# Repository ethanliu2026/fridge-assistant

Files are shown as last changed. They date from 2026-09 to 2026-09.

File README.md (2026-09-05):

# fridge-assistant
**An on-device smart fridge assistant that detects food and suggests recipes — no cloud, no subscription.**

FridgeAssistant is a physical-computing system that identifies the ingredients in your fridge using a custom-trained computer-vision model, then generates a cuisine-specific recipe from them using a language model running **entirely locally** on a Raspberry Pi 5. A 3D-printed robotic arm swings a camera into the fridge to scan, then retracts.

Everything runs offline on ~$150 of hardware — compared to $3,000+ smart fridges that depend on the cloud and still don't generate recipes.

<!-- 👇 REPLACE with your demo GIF/video. A short clip of "press deploy → arm scans → recipe appears" is the single most valuable thing in this README. -->
<!-- ![demo](media/demo.gif) -->
Watch the full video: https://youtu.be/iBZBi5uDBYY

---

## What it does

1. Pick a cuisine (Chinese / Italian / Japanese) with a button
2. Press **Deploy** — a 3D-printed arm swings a camera down into the fridge
3. A **custom-trained YOLOv8 model** detects food items in the live camera feed
4. Press **Deploy** again to lock the detected ingredients
5. The ingredient list is sent to **Llama 3.2 (3B)**, running locally via **Ollama**, which returns a recipe — dish name, method, and any missing ingredients
6. The recipe shows on screen; pressing **Deploy** once more retracts the arm

The model is trained to recognize 10 real fridge ingredients: **cabbage, carrot, chicken, cucumber, egg, garlic, mushroom, onion, potato, zucchini.**

## Why I built it

People open the fridge without knowing what they have or what to cook — leading to food waste, duplicate grocery runs, and unnecessary takeout. Existing options don't solve it well: smart fridges cost thousands and rely on the cloud, and pantry apps need you to manually log every item (most people quit within a week). FridgeAssistant automates detection and runs fully offline, keeping everything private and cheap.

## Tech stack

**Software:** Python · YOLOv8 (Ultralytics) · ONNX Runtime · Ollama (Llama 3.2 3B) · OpenCV · Tkinter · gpiozero · Adafruit ServoKit
**Hardware:** Raspberry Pi 5 (16GB) · Hailo-8L AI HAT+ · USB webcam · PCA9685 PWM driver · 4× MG90S servos · HW-131 power module (2× 18650)
**Fabrication:** 3D-printed arm links & camera mount (Fusion 360) · laser-cut acrylic base plate

## System architecture

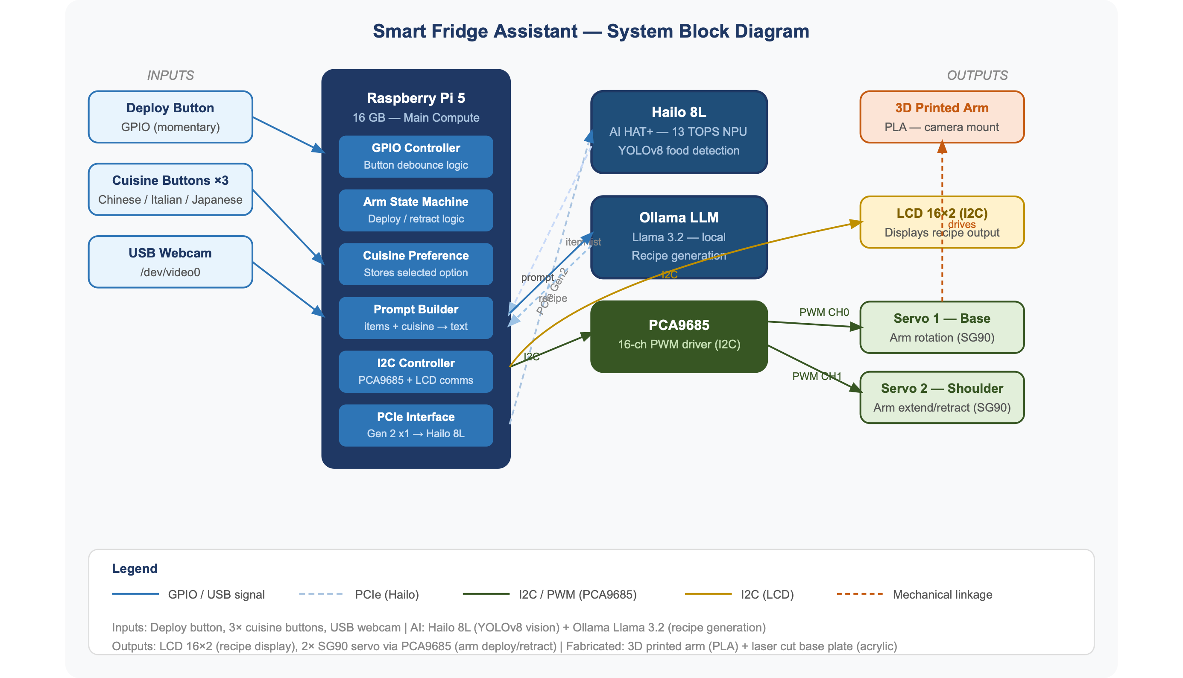
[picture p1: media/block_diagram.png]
System block diagram


```
Cuisine button → Pi 5 stores preference
Deploy button  → arm deploys (PCA9685 → 4× MG90S servos)
               → webcam captures fridge interior
               → YOLOv8 (best.onnx) detects food items
               → ingredient list + cuisine → Ollama (Llama 3.2)
               → recipe returned → displayed on screen
Deploy again   → arm retracts to parked position
```

The software runs **three concurrent threads**: the Tkinter UI loop, a camera-capture thread (~30 fps), and a detection thread (~1 fps) that runs inference on the latest frame. A three-state state machine (`IDLE → DEPLOYED → RECIPE`) drives the whole flow from a single deploy button.

## Design evolution

This was built across six iterations, each solving a concrete problem:

- **v1–v2** — Integrated the Hailo GStreamer pipeline with the UI and servos, using the stock COCO YOLOv8 model. Problems: GStreamer's signal handlers only work in the main thread, and the COCO model detected generic objects (donut, banana) rather than real fridge ingredients.
- **v3–v4** — Replaced the GStreamer pipeline with Ultralytics YOLO running a **custom-trained `best.onnx`** model on the CPU. Traded NPU acceleration for reliability and clean threading; added the 10 custom food classes.
- **v5** — Added the three-state state machine and fixed detection accumulation so items found across multiple frames persist instead of being overwritten. Integrated Ollama via `subprocess` with prompt engineering for a 3-sentence recipe.
- **v6 (final)** — Full three-thread architecture, smooth servo interpolation with I²C retry logic, ANSI-code stripping on the LLM output, and calibrated deploy/retract sequencing to avoid mechanical collision.

## Engineering challenges solved

A few of the more interesting problems from the build (full log in [`hardware/`](hardware/)):

- **I²C bus speed:** the Pi 5's I²C controller runs at 97.5 kHz — too fast for the PCF8574T LCD backpack (`Errno 121`). After trying baud-rate configs and a software-I²C overlay, pivoted to an HDMI display.
- **Servo torque:** SG90 servos overheated and stalled trying to lift the arm — upgraded to metal-gear MG90S.
- **Bus instability:** four servos moving at once crashed the I²C bus until a proper common ground was established between the HW-131 power module and the Pi.
- **UI freezing:** detection was blocking the UI thread — split camera capture and inference into separate threads.
- **Camera init:** the Pi needs a ~2 s delay after opening the USB camera or `VideoCapture` fails.

## Hardware & wiring

<details>
<summary>Raspberry Pi 5 pin assignments</summary>

| GPIO (BCM) | Physical Pin | Connected To | Function |
|---|---|---|---|
| GPIO 2 (SDA) | 3 | PCA9685 SDA | I²C data |
| GPIO 3 (SCL) | 5 | PCA9685 SCL | I²C clock |
| GPIO 17 | 11 | Button OUT 1 | Deploy |
| GPIO 27 | 13 | Button OUT 2 | Chinese cuisine |
| GPIO 22 | 15 | Button OUT 3 | Italian cuisine |
| GPIO 23 | 16 | Button OUT 4 | Japanese cuisine |
| 3.3V | 1 | Button VCC | Button logic power |
| GND | 6 | Common ground bus | Shared ground |

Buttons are **active-HIGH** (`pull_up=False`).

</details>

<details>
<summary>PCA9685 servo driver & power</summary>

| PCA9685 | Connected To | Notes |
|---|---|---|
| VCC | HW-131 3.3V | Logic power (not Pi 3.3V — insufficient current) |
| V+ | HW-131 5V | Servo power rail (external supply) |
| GND | Common ground bus | **Must** share ground with Pi for I²C stability |
| SDA / SCL | GPIO 2 / GPIO 3 | I²C |
| CH1–CH4 | 4× MG90S (signal only) | Channel map in code: `CHANNELS = [4, 1, 2, 3]` (CH0 was faulty) |

Power: 2× 18650 (7.4 V) → HW-131 buck module → 5 V servo rail + 3.3 V logic.

</details>

Fabrication files are in [`hardware/`](hardware/): arm links (`.stl`) and the base plate (`.dxf`).

## Running it

> ⚠️ This is built for a **Raspberry Pi 5 with attached servo hardware** — it won't run end-to-end on a normal computer without the arm, PCA9685, and camera. The code and model are provided for reference and reproduction.

```bash
# On a Raspberry Pi 5 with the hardware attached:
pip install ultralytics opencv-python pillow gpiozero adafruit-circuitpython-servokit

# Install Ollama and pull the model
curl -fsSL https://ollama.com/install.sh | sh
ollama pull llama3.2:3b

# Update the model path in fridge_assistant.py to point to best.onnx, then:
python fridge_assistant.py
```

## Repository contents

| File | Description |
|---|---|
| `fridge_assistant.py` | Final integrated application (v6) |
| `best.onnx` | Custom-trained YOLOv8 model (10 food classes) |
| `media/block_diagram.png` | System architecture diagram |
| `hardware/` | 3D-print (`.stl`) and laser-cut (`.dxf`) fabrication files |

---

*Built as the capstone for Advanced Physical Computing (2025–2026). Combines a custom-trained vision model and a locally-run LLM on embedded hardware into a single working physical system.*

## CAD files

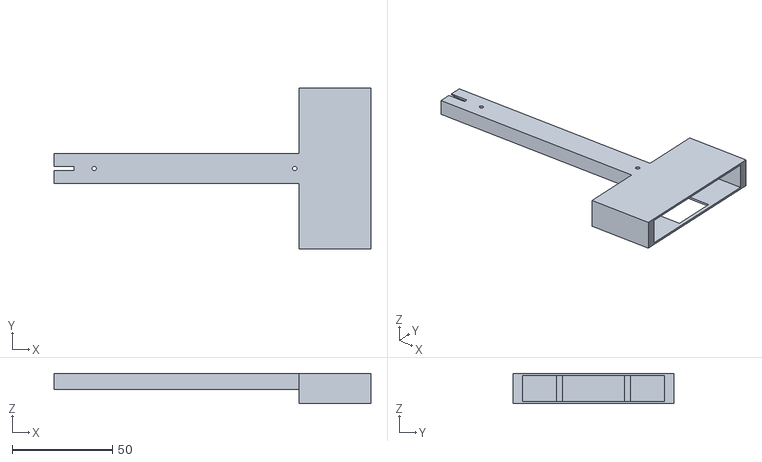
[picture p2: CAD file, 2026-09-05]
cad/link 1 v6.stl
158.0 x 80.0 x 15.0

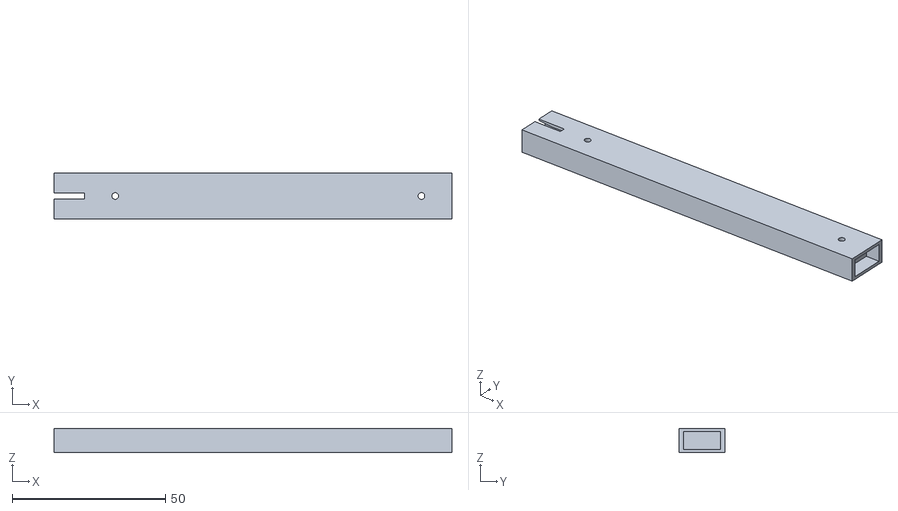
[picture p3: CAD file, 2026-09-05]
cad/link 2 v3.stl
130.0 x 15.0 x 8.00

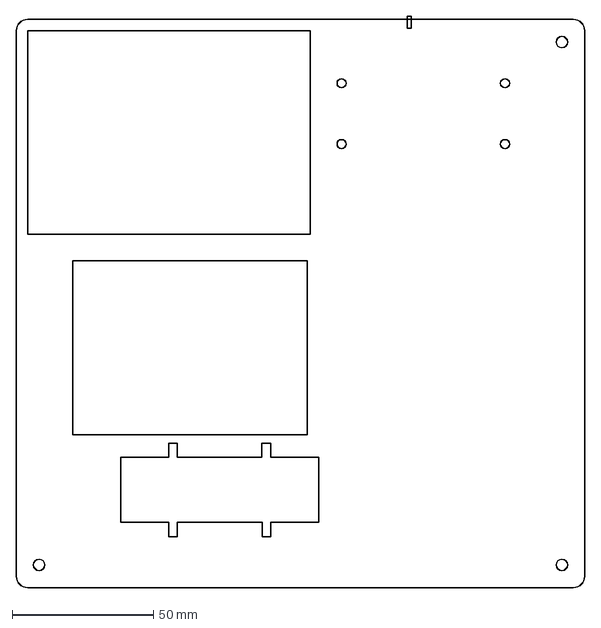
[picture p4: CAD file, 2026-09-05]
cad/APC base plate v3.dxf
201.1 x 202.1 mm

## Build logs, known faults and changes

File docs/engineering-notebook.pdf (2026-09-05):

Advanced Physical Computing 2025-2026 Capstone Project

## Smart Fridge Inventory & Recipe Assistant

Submitted by

## Ethan Liu

## Shanghai American School Puxi

Date: April 2026

Platform: Raspberry Pi 5 + Hailo 8L AI HAT+ + Ollama

### __________________________________________________________

## Table of Contents

### Executive Summary

The Smart Fridge Assistant is an AI-powered physical computing system that automatically identifies food ingredients in a refrigerator and generates cuisine-specific recipe suggestions. The system addresses a common daily problem: people open their fridge not knowing what to cook, leading to food waste, duplicate grocery purchases, and unnecessary takeout.

The system consists of a 3D-printed robotic arm mounted on a laser-cut base plate on top of a refrigerator. When the user presses the deploy button, the arm swings down into the fridge opening using four MG90S servos driven by a PCA9685 PWM driver. A USB webcam at the end of the arm captures the fridge interior. A custom-trained YOLOv8 object detection model running on the Raspberry Pi 5 identifies food items including eggs, potatoes, onions, carrots, garlic, mushrooms, cabbage, chicken, cucumber, and zucchini. The detected ingredients are passed to Ollama running Llama 3.2 3B locally on the Pi, which generates a recipe suggestion tailored to the user's selected cuisine preference (Chinese, Italian, or Japanese). The recipe — including dish name, preparation method, and any missing ingredients — is displayed on screen. Pressing the deploy button again retracts the arm to its parked position.
The system runs entirely offline with no cloud dependency, costs approximately $150 in hardware compared to $3,000+ smart fridge solutions, and responds in under 30 seconds from deploy to recipe display.

Key technical challenges overcome included Pi 5 I2C bus incompatibility with the LCD display, servo torque limitations requiring an upgrade from SG90 to MG90S, power instability from inadequate common grounding, and camera initialization timing issues. The Hailo-8 AI HAT+ is integrated into the system and detected successfully, providing the hardware foundation for future YOLOv8 NPU acceleration planned as an extension of this project.

## 1.Problem Statement

### 1.1 The Problem

People open their fridge multiple times a day not knowing what they have, what’s running low, or what they an cook with what’s available. This leads to food waste (buying duplicates of things already in the fridge), unnecessary grocery trips, and the daily frustration of staring into the fridge trying to decide what to make.

### 1.2 Target Customer

Anyone who cooks at home, particularly students living independently, busy families, and households where multiple people share a fridge and nobody tracks inventory.

### 1.3 Solution Usage

A camera mounted at the fridge door automatically scans visible food items when the door opens, identifies them using AI vision, and immediately suggests recipes based on what’s available. A physical indicator flags when stock is critically low.

## 2. Research

### 2.1 What already exists

- Samsung Family Hub fridge — built-in interior camera, app-based viewing, cloud processing, no recipe generation. Costs $3000+, requires internet, camera is fixed and fogs up from condensation.
- LG ThinQ fridge — similar concept, app-based, cloud dependent, expensive.
- Grocy / pantry apps — manual barcode scanning to log inventory. Relies entirely on user discipline — most people stop using it within a week.
- ChatGPT / recipe apps — require you to manually type what you have. No automatic detection.
- Fixed fridge cameras (e.g. FridgeCam) — small camera that mounts inside and photos contents when door closes. Still suffers from condensation, fixed angle, no AI processing.

### 2.2 What I Learned from Research

- COCO-trained YOLOv8 can detect ~20 common food items out of the box (banana, apple, orange, sandwich, bottle, cup, bowl, cake, carrot, hot dog, pizza, donut, broccoli) — sufficient for a meaningful demo
- Ollama can run Llama 3.2 or Gemma 3 locally on Pi 5 — response time is ~3-8 seconds for a short recipe suggestion, acceptable for this use case
- PCA9685 can drive multiple servos simultaneously over I2C from just 2 GPIO pins, solving the PWM pin limitation on Pi 5
- A 2-servo arm (base rotation + shoulder extension) is sufficient to move a lightweight USB camera from a parked position on top of the fridge to a scanning position inside the fridge opening

[Example] The following, Figure 1, depicts the three-view of the final unmanned system design.

[ADD FIGURE-CENTERED]

Figure 1. Three-view of final uncrewed system design.

## 3.System Architecture

### 3.1 Component List:

Component | Part | Role
Raspberry Pi 5 (16GB) | RPi 5 16GB | Main compute
Hailo 8L AI HAT+ | 13 TOPS NPU | Runs YOLOv8 food detection
USB Webcam | Logitech C270 or similar | Captures fridge interior
Push button (deploy) | Momentary tactile button | Triggers arm deploy/retract cycle
Push button (Chinese) | Momentary tactile button | Selects Chinese cuisine preference
Push button (Italian) | Momentary tactile button | Selects Italian cuisine preference

Push button (Japanese) | Momentary tactile button | Selects Japanese cuisine preference
PCA9685 PWM driver | Adafruit PCA9685 | Controls both servos over I2C
SG90 Servo 1 | SG90 | Base rotation (arm swings out over fridge)
SG90 Servo 2 | SG90 | Shoulder (arm extends down into fridge)
LCD 16x2 (I2C) | LCD1602 with I2C backpack | Displays detected items + recipe
3D printed arm | Bambu Lab PLA | Arm links + camera mount at end effector
Laser cut base plate | 3mm acrylic | Mounts PCA9685, Pi, and arm base to fridge top

### 3.2 Data Flow:

Cuisine button pressed (Chinese / Italian / Japanese) ↓
Pi 5 stores selected cuisine preference
↓
Deploy button pressed
↓
GPIO detects press → arm deploys
(PCA9685 → Servo 1 rotates out, Servo 2 extends down) ↓
Webcam captures frame of fridge interior
↓
Hailo 8L runs YOLOv8 inference on frame
↓
Detected food items list (class labels + confidence scores) ↓
Filter detections by confidence threshold (>0.5)
↓
Item list + cuisine preference formatted as prompt
→ sent to Ollama (Llama 3.2):
"Given these ingredients: [items]. Suggest a [cuisine] recipe."

↓
Ollama returns recipe suggestion
↓
LCD displays recipe (scrolling if text exceeds 2 lines)
↓
Deploy button pressed again → arm retracts to parked position (PCA9685 → Servo 2 retracts, Servo 1 rotates back)

### 3.3 Block Diagram

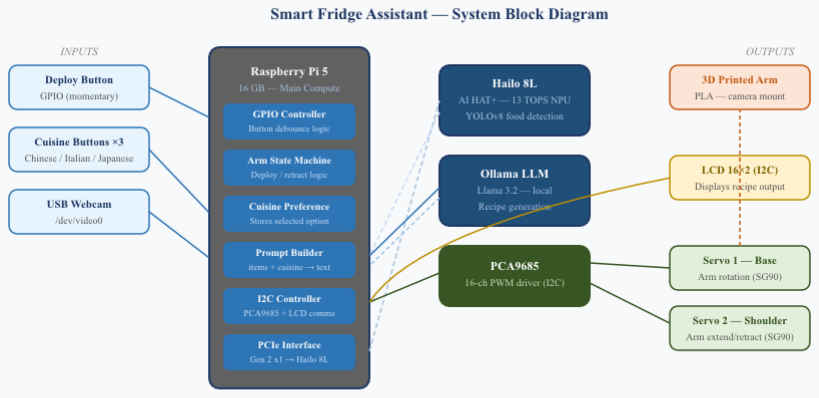
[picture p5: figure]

## 4. Wiring Diagram & Pin Assignment

### 4.1 Raspberry Pi Pin Assignment Table

GPIO (BCM) | Physical Pin | Connected To | Function
GPIO 2 (SDA) | Pin 3 | PCA9685 SDA, LCD SDA | I2C data
GPIO 3 (SCL) | Pin 5 | PCA9685 SCL, LCD SCL | I2C clock
GPIO 17 | Pin 11 | Button module OUT 1 | Deploy button
GPIO 27 | Pin 13 | Button module OUT 2 | Chinese cuisine
GPIO 22 | Pin 15 | Button module OUT 3 | Italian cuisine

GPIO 23 | Pin 16 | Button module OUT 4 | Japanese cuisine
3.3V | Pin 1 | Button module VCC | Button logic power
5V | Pin 2 | LCD VCC | LCD panel power
GND | Pin 6 | Common ground bus | Shared ground
USB-A | — | USB Webcam | Camera input
PCIe FPC | — | Hailo-8 AI HAT+ | NPU connection
HDMI | — | Monitor | Display output

### 4.2 PCA9685 PWM Driver Connections

PCA9685 Pin | Connected To | Notes
VCC | HW-131 3.3V output | Logic power — NOT Pi 3.3V (insufficient current)
GND | Common ground bus | Must share ground with Pi
SDA | GPIO 2 (Pi pin 3) | I2C data
SCL | GPIO 3 (Pi pin 5) | I2C clock
V+ | HW-131 5V output | Servo power rail — external supply required
CH1 PWM | MG90S Servo (middle joint 1) | Signal wire only
CH2 PWM | MG90S Servo (base joint 1) | Signal wire only
CH3 PWM | MG90S Servo (middle joint 2) | Signal wire only
CH4 PWM | MG90S Servo (base joint 2) | Signal wire only

### 4.3 HW-131 Power Module

HW-131 Pin | Connected To | Notes
Input+ | 18650 battery pack positive | 7.4V input from 2× NCR18650B
Input- | 18650 battery pack negative | —
5V output | PCA9685 V+ | Servo power
3.3V output | PCA9685 VCC | Logic power
GND | Pi GND (pin 6) + PCA9685 GND | Common ground — critical for I2C stability

## 5. Code Documentation & Explanation

### 5.1 Version History

### 5.1.1 fridge_assistant_v1-v2 (Early Versions)

Initial integration attempts combining the Hailo GStreamer pipeline with tkinter display and servo control. These versions used the default COCO YOLOv8 model running on the Hailo-8 NPU via the hailo-apps GStreamer pipeline.

Problems encountered:
- GStreamer pipeline requires signal handlers that only work in the main thread — running it in a background thread caused ValueError: signal only works in main thread
- Default COCO model detected general objects (person, donut, banana) but not realistic fridge ingredients
- LCD display integration failed due to Pi 5 I2C bus speed incompatibility

### 5.1.2 fridge_assistant_v3-v4 (ONNX Transition)

Replaced Hailo GStreamer pipeline with ultralytics YOLO running the custom-trained best.onnx model directly. This sacrifices NPU acceleration (model runs on CPU) in exchange for reliability and compatibility with threading.

Key change:
- Detection now uses YOLO('/home/stussy/Downloads/best.onnx', task='detect') with onnxruntime backend. Runs at approximately 1 frame per second on Pi 5 CPU, acceptable for a fridge scanning use case.
- Added custom food classes from trained dataset: cabbage, carrot, chicken, cucumber, egg, garlic, mushroom, onion, potato, zucchini.

### 5.1.3 fridge_assistant_v5 (State Machine)

Introduced a 3-state state machine to control program flow:

## STATE_IDLE → (deploy press) → STATE_DEPLOYED → (deploy press) → STATE_RECIPE → (deploy press) → STATE_IDLE

- STATE_IDLE: Arm parked, waiting for user input
- STATE_DEPLOYED: Arm down, camera scanning, detections accumulate across frames
- STATE_RECIPE: Items locked, Ollama generating recipe, displaying result

Detection accumulation fix: Changed user_data.live_items = list(set(items)) to user_data.live_items = list(set(user_data.live_items + items)) so items detected across multiple frames are preserved rather than replaced each frame.
Ollama integration: Uses subprocess.run(['ollama', 'run', 'llama3.2:3b', prompt]) with 120s timeout. Prompt engineered to return dish name, cooking description, and missing ingredients in 3 sentences.

### 5.1.4 fridge_assistant_v6 (Final Version)

Final integrated script with all features working:
Architecture — 3 concurrent threads:
- Main thread: tkinter event loop and UI updates
- run_camera: captures frames at 30fps, stores in user_data.latest_frame
- run_detection: runs YOLO inference at 1fps using latest frame, updates detected items

Key Functions:
- move_joint(indices, targets, steps, delay) — smooth servo interpolation. Takes position indices (0-3) mapped through CHANNELS=[4,1,2,3] to actual PCA9685 channels. Moves in 15 steps with 0.08s delay between steps for smooth motion. Includes retry logic for I2C errors.
- deploy_arm() / retract_arm() — sequence control. Deploy moves middle joint first then base to avoid mechanical collision. Retract reverses: middle first, then base.
- on_deploy() — state machine transition handler. Single button controls all three state transitions depending on current state.

- get_recipe() — runs in separate thread to avoid blocking UI. Strips ANSI escape codes from Ollama output using re.sub(r'\x1b\[[0-9;]*m', '', recipe) before displaying.
- update_camera() — tkinter after() callback running every 50ms, converts OpenCV BGR frame to PIL ImageTk for display in left panel.
- CHANNELS mapping: CHANNELS = [4, 1, 2, 3] maps position indices to PCA9685 channels. Index 0 = CH4 (base servo 1), Index 1 = CH1 (middle servo 1), Index 2 = CH2 (base servo 2), Index 3 = CH3 (middle servo 2). CH0 was found to be faulty and replaced with CH4.

### 5.2 Final Code (v6)

import cv2 import subprocess import time import threading import tkinter as tk from PIL import Image, ImageTk from gpiozero import Button from adafruit_servokit import ServoKit from ultralytics import YOLO

SERVO SETUP

kit = ServoKit(channels=16) for ch in [1, 2, 3, 4]: kit.servo[ch].set_pulse_width_range(600, 2400) time.sleep(0.5)

CHANNELS = [4, 1, 2, 3] PARKED = [65, 125, 97, 20] DEPLOYED = [115, 75, 47, 70]

pos = PARKED[:]

def set_servo(ch, angle): angle = max(0, min(180, int(angle))) for attempt in range(4): try: kit.servo[ch].angle = angle return except Exception as e: print(f"CH{ch} retry {attempt+1}: {e}") time.sleep(0.3)

def move_joint(indices, targets, steps=15, delay=0.08): start = pos[:] for i in range(1, steps + 1): for idx in indices: new = int(start[idx] + (targets[idx] - start[idx]) * i / steps) new = max(0, min(180, new)) set_servo(CHANNELS[idx], new) time.sleep(0.04) time.sleep(delay) for idx in indices: pos[idx] = targets[idx]

def deploy_arm(): display("Deploying arm...") mid_targets = pos[:] mid_targets[1] = DEPLOYED[1] mid_targets[3] = DEPLOYED[3] move_joint([1, 3], mid_targets) time.sleep(0.5) base_targets = pos[:] base_targets[0] = DEPLOYED[0] base_targets[2] = DEPLOYED[2] move_joint([0, 2], base_targets)

def retract_arm(): display("Retracting...") base_targets = pos[:] base_targets[0] = PARKED[0] base_targets[2] = PARKED[2] move_joint([0, 2], base_targets) time.sleep(0.5) mid_targets = pos[:] mid_targets[1] = PARKED[1] mid_targets[3] = PARKED[3] move_joint([1, 3], mid_targets)

DISPLAY SETUP

root = tk.Tk() root.title("Fridge Assistant") root.configure(bg="black") root.attributes('-fullscreen', True) root.update() SW = root.winfo_width() SH = root.winfo_height()

Left panel — camera feed

cam_label = tk.Label(root, bg="black") cam_label.place(x=0, y=0, width=SW//2, height=SH)

Right panel — info

right = tk.Frame(root, bg="black") right.place(x=SW//2, y=0, width=SW//2, height=SH)

tk.Label(right, text="Fridge Assistant", font=("Arial", 32, "bold"), bg="black", fg="white").pack(pady=20)

cuisine_label = tk.Label(right, text="Cuisine: Chinese", font=("Arial", 22), bg="black", fg="yellow") cuisine_label.pack(pady=5)

status_label = tk.Label(right, text="Select cuisine → Deploy", font=("Arial", 18), bg="black", fg="green") status_label.pack(pady=5)

detected_label = tk.Label(right, text="", font=("Arial", 16), bg="black", fg="cyan", wraplength=SW//2 -
40) detected_label.pack(pady=5)

recipe_label = tk.Label(right, text="", font=("Arial", 15), bg="black", fg="white", wraplength=SW//2 - 40, justify="left") recipe_label.pack(pady=10, padx=20)

hint_label = tk.Label(right, text="", font=("Arial", 14, "italic"), bg="black", fg="gray") hint_label.pack(pady=5)

QUIT BUTTON

quit_btn = tk.Button(right, text="✕ Quit", font=("Arial", 14), bg="#333333", fg="white", relief="flat", command=lambda: quit_program()) quit_btn.pack(side="bottom", pady=20)

def display(status="", recipe="", detected="", hint=""): status_label.config(text=status) recipe_label.config(text=recipe) detected_label.config(text=detected) hint_label.config(text=hint) root.update()

def quit_program(): print("Quitting...") retract_arm() root.destroy()

STATE

STATE_IDLE = 0 STATE_DEPLOYED = 1 STATE_RECIPE = 2 state = STATE_IDLE

class UserData: def init(self): self.live_items = [] self.locked_items = [] self.cuisine = "Chinese" self.latest_frame = None

user_data = UserData()

CAMERA FEED UPDATE

def update_camera(): if user_data.latest_frame is not None: frame = user_data.latest_frame.copy() frame = cv2.cvtColor(frame, cv2.COLOR_BGR2RGB) h, w = frame.shape[:2] # Scale to fit left panel panel_w = SW // 2 panel_h = SH scale = min(panel_w / w, panel_h / h) new_w = int(w * scale) new_h = int(h * scale) frame = cv2.resize(frame, (new_w, new_h)) img = ImageTk.PhotoImage(Image.fromarray(frame)) cam_label.config(image=img) cam_label.image = img root.after(50, update_camera)

DETECTION LOOP

def run_detection(): model = YOLO('/home/stussy/Downloads/best.onnx', task='detect') cap = cv2.VideoCapture(0) FOOD_CLASSES = { "cabbage", "carrot", "chicken", "cucumber", "egg", "garlic", "mushroom", "onion", "potato", "zucchini" }

while True:
ret, frame = cap.read() if not ret: time.sleep(0.1)
continue

if state == STATE_DEPLOYED:
results = model(frame, verbose=False) items = []
for r in results:
for box in r.boxes:
label = model.names[int(box.cls)]
conf = float(box.conf)
if conf > 0.35 and label in FOOD_CLASSES: items.append(label)
# Draw box on frame

x1, y1, x2, y2 = map(int, box.xyxy[0]) cv2.rectangle(frame, (x1, y1), (x2, y2), (0, 255, 255), 2) cv2.putText(frame, f"{label} {conf:.2f}",
(x1, y1 - 8), cv2.FONT_HERSHEY_SIMPLEX, 0.5, (0, 255, 255), 2)

if items:
user_data.live_items = list(set(user_data.live_items + items)) items_str = ", ".join(sorted(user_data.live_items)) detected_label.config(text=f"Detected: {items_str}") root.update()

user_data.latest_frame = frame
time.sleep(0.05)

OLLAMA def get_recipe(): items_str = ", ".join(sorted(user_data.locked_items)) display( "Generating recipe...", detected=f"Locked: {items_str}", hint="Please wait..." ) prompt = ( f"I found these ingredients in my fridge: {items_str}. " f"Suggest ONE simple {user_data.cuisine} recipe I could make. " f"In 3 sentences: name the dish, briefly describe how to make it, " f"then list any extra ingredients I would need." ) try: result = subprocess.run( ["ollama", "run", "llama3.2:3b", prompt], capture_output=True, text=True, timeout=120 ) recipe = result.stdout.strip() display( f"{user_data.cuisine} Recipe", recipe=recipe, detected=f"Ingredients: {items_str}", hint="Press Deploy to retract arm" ) except Exception as e: display("Ollama error", recipe=str(e)[:80])

BUTTON CALLBACKS

def on_deploy(): global state
if state == STATE_IDLE:
state = STATE_DEPLOYED
user_data.live_items = []
def do_deploy():
deploy_arm()
display(
"Scanning fridge...",
detected="Looking for food...",
hint="Press Deploy again to lock items & get recipe" )
threading.Thread(target=do_deploy, daemon=True).start()

elif state == STATE_DEPLOYED:
if not user_data.live_items:
display("No food detected!", hint="Try adjusting camera angle") return
state = STATE_RECIPE
user_data.locked_items = user_data.live_items[:] threading.Thread(target=get_recipe, daemon=True).start()

elif state == STATE_RECIPE:

state = STATE_IDLE
user_data.live_items = []
user_data.locked_items = []
def do_retract():
retract_arm()
display("Ready!", hint="Select cuisine then press Deploy") threading.Thread(target=do_retract, daemon=True).start()

def on_chinese(): user_data.cuisine = "Chinese" cuisine_label.config(text="Cuisine: Chinese") root.update()

def on_italian(): user_data.cuisine = "Italian" cuisine_label.config(text="Cuisine: Italian") root.update()

def on_japanese(): user_data.cuisine = "Japanese" cuisine_label.config(text="Cuisine: Japanese") root.update()

btn_deploy = Button(17, pull_up=False) btn_chinese = Button(27, pull_up=False) btn_italian = Button(22, pull_up=False) btn_japanese = Button(23, pull_up=False)

btn_deploy.when_pressed = on_deploy btn_chinese.when_pressed = on_chinese btn_italian.when_pressed = on_italian btn_japanese.when_pressed = on_japanese

STARTUP

print("Starting Fridge Assistant...")

for i, ch in enumerate(CHANNELS): set_servo(ch, PARKED[i]) time.sleep(1.5)

display("Fridge Assistant ready!", hint="Select cuisine then press Deploy")

detection_thread = threading.Thread(target=run_detection, daemon=True) detection_thread.start()

root.after(100, update_camera)

MAIN LOOP try: root.mainloop() except KeyboardInterrupt: print("\nShutting down...") retract_arm() root.destroy()

## 6. Fusion 360 Design Files & Iteration Notes

### 6.1 Base Plate – 2 iterations

### 6.1.1 Iteration 1 (Cardboard)

Final integrated script with all features working:

A rough cardboard prototype with approximate hole positions for the base servos and PCA9685. This was used to verify the general layout and spacing before committing to a permanent material. Holes were laser-cut and approximate.

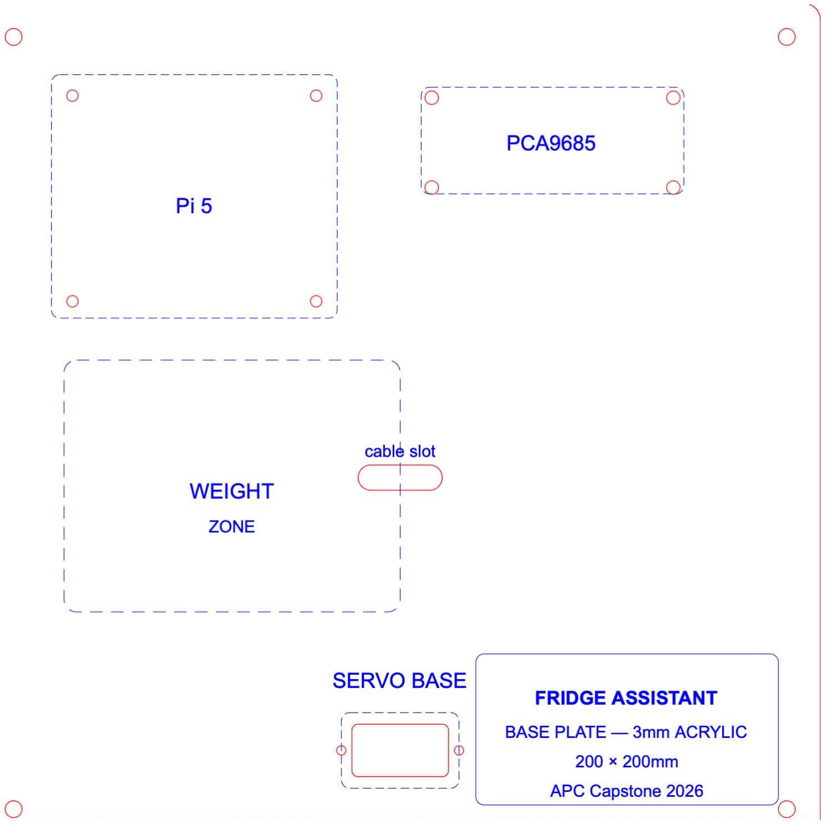
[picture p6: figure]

Figure 2. Iteration 1 of the Base Plate

### 6.1.2 Iteration 2 (Wood)

Final integrated script with all features working:

A rough cardboard prototype with approximate hole positions for the base servos and PCA9685. This was used to verify the general layout and spacing before committing to a permanent material. Holes were hand-cut and approximate — no precise measurements.

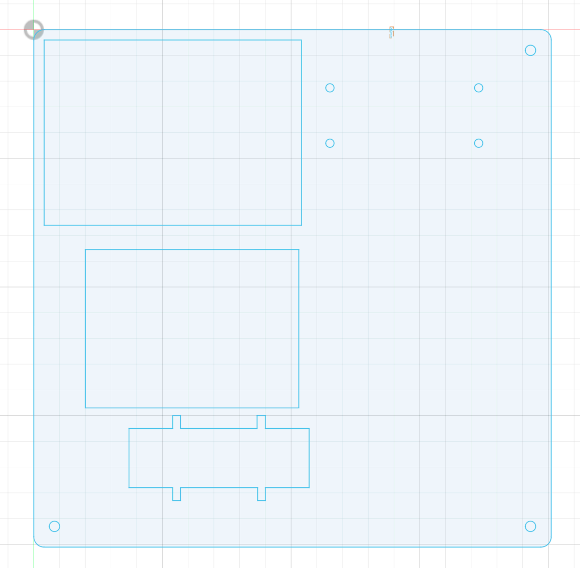
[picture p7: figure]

Figure 2. Iteration 2 of the Base Plate

Key learning: The cardboard prototype saved significant time — discovering that the servo spacing needed adjustment before cutting the final material avoided wasting a wood sheet.

### 6.2 Arm Links – 2 iterations

### 6.2.1 Iteration 1

Simple rectangular beam with flat ends. Connected to servo horns using hot glue — unreliable under torque and came loose during testing.

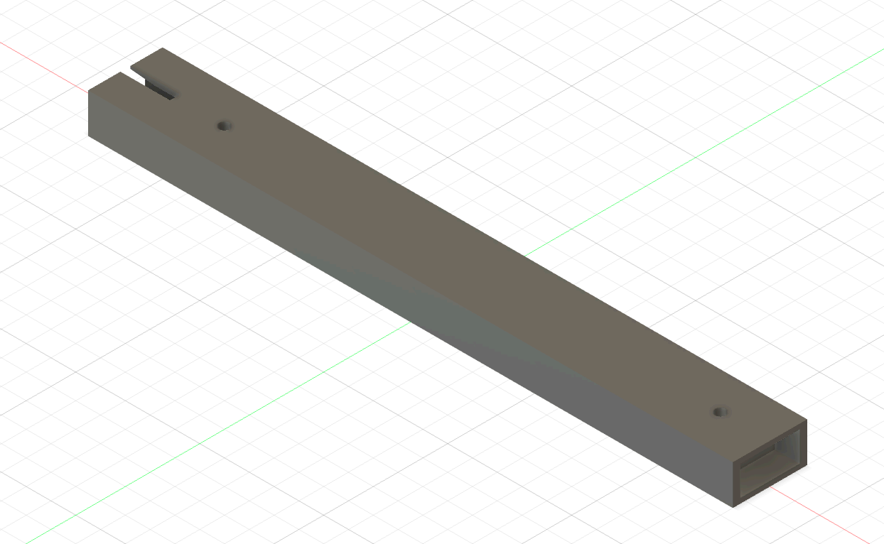
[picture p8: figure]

Figure 1. Iteration 1 of the Arm Link

### 6.2.2 Iteration 2

Added recessed slots at the joint ends sized to the servo horn profile, so the horn sits flush and is mechanically located before any adhesive is applied. For the dual-servo base joint, replaced the simple flat plate with measured slots that the MG90S servo bodies press-fit into precisely, eliminating reliance on hot glue for alignment.

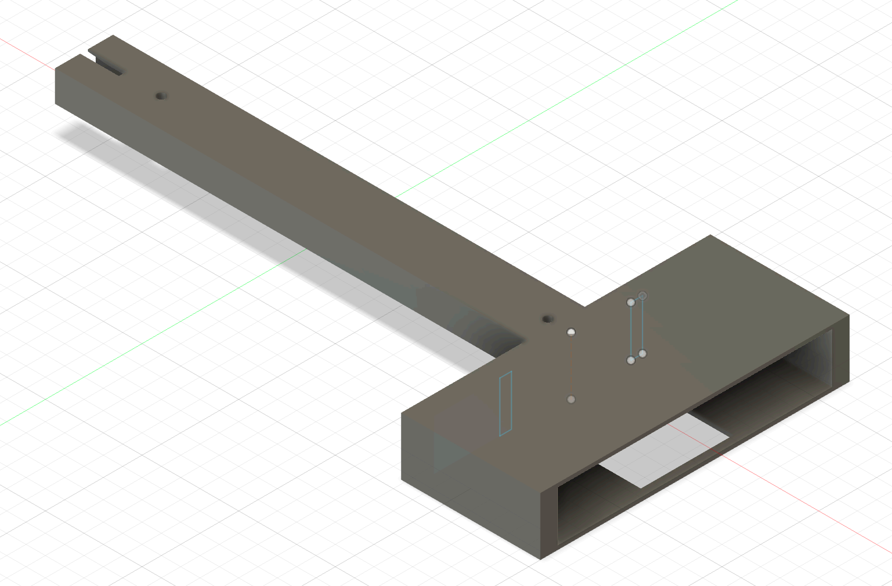
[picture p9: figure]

Figure 2. Iteration 2 of the Base Plate

Key learning: Mechanical location is far more reliable than adhesive alone under repeated servo movement. The press-fit slots made the joint significantly more stable.

## 7. Testing Logs

Date | Component | What was tested | Result | Fix applied
Mar | LCD (16×2 I2C) | Display text via RPLCD | Failed — OSError Errno 121 Remote I/O error | Discovered Pi 5 brcmstb I2C controller runs at 97.5kHz — too fast for PCF8574T. Attempted baudrate config, software I2C overlay.

| | | | Unresolved — pivoted to HDMI display
Mar | PCA9685 | i2cdetect | Detected at 0x40 ✓ | —
Mar | SG90 servos × 4 | Basic angle movement | Moved correctly individually | —
Mar | SG90 servos × 4 | All 4 moving simultaneously | I2C crashed mid-run (Errno 121) | Fixed common ground between HW-131 power module and Pi — voltage difference was causing bus instability
Mar | SG90 servos | Arm lift test | Servos overheated and stalled — insufficient torque to lift arm weight | Upgraded to MG90S metal gear servos
Mar | MG90S servos | Arm lift test | Successfully lifted arm ✓ | Calibrated PARKED and DEPLOYED angles per channel
Apr | Hailo-8 | hailortcli fw-control identify | Detected: Firmware 4.23.0, HAILO8 architecture ✓ | —
Apr | Buttons × 4 | GPIO input test | Initially read as always pressed | Changed pull_up=True to pull_up=False — button modules are active HIGH
Apr | Ollama | Recipe generation | Worked but slow (~30s) and initial timeout errors | Increased timeout to 120s, shortened prompt
Apr | Ollama output | Display on screen | Random characters appeared (□[7D□[K) | Stripped ANSI escape codes with regex
May | USB webcam | cv2.VideoCapture(0) | Failed — camera not found | Added 2-second delay after opening — Pi needs time to initialize USB camera

May | Custom YOLOv8 (5 epochs) | Potato detection | Detected as onion/donut | Retrained for 10 epochs — improved but still imperfect
May | Camera feed | Display in tkinter window | Frame frozen — detection blocking UI thread | Separated into two threads: run_camera (30fps) and run_detection (1fps)
May | Full system | End-to-end flow | Working ✓ | —

## 8. AI Usage Log

This project was developed with significant AI assistance through Claude (Anthropic). Below is a summary of how AI was used and the decisions made:
- Hardware debugging
- AI was used extensively to diagnose the I2C LCD issue. Claude identified that the Pi 5's new brcmstb I2C controller runs at a fixed 97.5kHz and doesn't respond to standard baudrate configuration — a known Pi 5-specific issue. Multiple approaches were suggested (baudrate config, software I2C overlay, different GPIO pins). When all failed, the decision to pivot to HDMI display was made by the student after weighing time cost vs. benefit.
- Code architecture
- Claude generated the initial script structure including the state machine (IDLE → DEPLOYED → RECIPE), servo movement functions with smooth interpolation, and the threading architecture separating camera capture from detection. The student made decisions about servo channel assignments, calibrated angles, and button GPIO pins based on physical testing.
- Servo calibration
- The calibration process was entirely student-driven — the student ran test scripts, physically observed servo movement, and reported back observed angles. AI provided the test code framework but the student determined all PARKED and DEPLOYED values through hands-on iteration.
- Detection and Ollama
- Claude suggested switching from the Hailo GStreamer pipeline to ultralytics ONNX inference when the pipeline couldn't run in a background thread. The student decided to use a Roboflow public dataset for training rather than building a custom dataset from scratch, based on time constraints. Prompt engineering for Ollama (asking for dish name, description, and missing ingredients) was a collaborative decision.
- Key principle
- AI was used as a technical reference and code generation tool. All hardware decisions, physical calibration, and design tradeoffs were made by the student based on real-world testing results.

## 9. Reflection

This project pushed me significantly beyond the scope of standard coursework. Building a system that combines physical robotics (a 4-servo arm driven by a PCA9685), computer vision (custom-trained YOLOv8), and a local language model (Ollama Llama 3.2) into a single integrated pipeline required coordinating hardware, firmware, and software layers simultaneously — a level of complexity I hadn't encountered before.

The most valuable learning was about the gap between theory and practice. The Raspberry Pi 5 introduced unexpected incompatibilities — its new I2C controller, PCIe interface, and GPIO behavior differ from older Pi models in ways that aren't always documented. What should have been a simple LCD connection turned into a multi-session debugging process that ultimately couldn't be resolved within the project timeline. This taught me to research hardware-specific issues before assuming standard approaches will work, and to have contingency plans.
The servo system also taught me about mechanical engineering tradeoffs. SG90 servos were sufficient in isolation but completely inadequate under the load of a 26cm arm with a camera at the end. Upgrading to MG90S and redesigning the 3D printed joints to use mechanical location instead of adhesive was a practical lesson in how real systems fail under conditions that weren't obvious during initial design.

The AI-assisted development process was a genuine productivity multiplier but required careful judgment. Claude could generate working code quickly, but it couldn't know the physical state of my hardware, the exact angles my servos were at, or why a particular wire connection was causing instability. Every AI suggestion had to be verified through physical testing, and many required modification based on what actually happened. The skill of knowing when to trust AI output and when to question it was as important as any technical knowledge.

If I were to redo this project, I would start with a power budget analysis before ordering any components — the current draw from four servos was a problem I didn't anticipate. I would also prototype the arm mechanism in cardboard before 3D printing to verify the mechanical design, which I did for the base plate but not the arm links, costing me two print iterations.

Overall this project successfully demonstrated that edge AI — running both vision inference and language model generation entirely on local hardware without internet — is genuinely practical at the hobbyist level. The Hailo-8 HAT+ and Raspberry Pi 5 together make what would have required cloud services just a few years ago possible on a $200 board.

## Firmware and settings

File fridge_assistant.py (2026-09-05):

import time
import subprocess
import cv2
from gpiozero import Button
from adafruit_servokit import ServoKit
from RPLCD.i2c import CharLCD

# ─── HARDWARE SETUP ───────────────────────────────────────────────
kit = ServoKit(channels=16)

# Servo pulse range for SG90
for ch in range(3):
    kit.servo[ch].set_pulse_width_range(500, 2500)

# LCD
lcd = CharLCD(i2c_expander='PCF8574', address=0x27, port=1, cols=16, rows=2, dotsize=8)

# Buttons (active HIGH — pull_up=False)
btn_deploy   = Button(17, pull_up=False)
btn_chinese  = Button(27, pull_up=False)
btn_italian  = Button(22, pull_up=False)
btn_japanese = Button(23, pull_up=False)

# ─── ARM POSITIONS ────────────────────────────────────────────────
# Adjust these angles after physical testing
ARM_PARKED   = (0, 0)    # (base_angle, elbow_angle) when arm is up
ARM_DEPLOYED = (90, 120) # angles when arm is inside fridge

# ─── STATE ────────────────────────────────────────────────────────
cuisine = "Chinese"  # default
arm_down = False

# ─── HELPERS ──────────────────────────────────────────────────────
def lcd_print(line1, line2=""):
    lcd.clear()
    lcd.cursor_pos = (0, 0)
    lcd.write_string(line1[:16])
    if line2:
        lcd.cursor_pos = (1, 0)
        lcd.write_string(line2[:16])

def move_arm(base_angle, elbow_angle, delay=0.8):
    """Move arm smoothly to target position."""
    kit.servo[0].angle = base_angle   # base servo 1
    kit.servo[1].angle = base_angle   # base servo 2 (same signal)
    time.sleep(0.3)
    kit.servo[2].angle = elbow_angle  # elbow
    time.sleep(delay)

def deploy_arm():
    print("Deploying arm...")
    lcd_print("Deploying arm...", "")
    move_arm(*ARM_DEPLOYED)

def retract_arm():
    print("Retracting arm...")
    lcd_print("Retracting...", "")
    # Retract elbow first, then base
    kit.servo[2].angle = ARM_PARKED[1]
    time.sleep(0.5)
    kit.servo[0].angle = ARM_PARKED[0]
    kit.servo[1].angle = ARM_PARKED[0]
    time.sleep(0.8)

def capture_frame():
    """Capture a single frame from the webcam."""
    cap = cv2.VideoCapture(0)
    time.sleep(0.5)  # let camera warm up
    ret, frame = cap.read()
    cap.release()
    if not ret:
        print("Failed to capture frame")
        return None
    cv2.imwrite("/tmp/fridge_scan.jpg", frame)
    return frame

def detect_food(frame):
    """
    Detect food items using YOLOv8 via hailo-apps.
    For now uses OpenCV color/object detection as fallback.
    Returns list of detected food item names.
    """
    # COCO food classes that YOLOv8 can detect
    food_classes = {
        46: "banana", 47: "apple", 48: "sandwich", 49: "orange",
        50: "broccoli", 51: "carrot", 52: "hot dog", 53: "pizza",
        54: "donut", 55: "cake", 39: "bottle", 40: "wine glass",
        41: "cup", 43: "knife", 44: "spoon", 45: "bowl"
    }

    try:
        # Try to use hailo detection pipeline
        result = subprocess.run(
            ["hailo-detect", "--input", "/tmp/fridge_scan.jpg",
             "--labels", "coco", "--threshold", "0.4"],
            capture_output=True, text=True, timeout=15
        )
        detected = []
        for line in result.stdout.split("\n"):
            for class_id, name in food_classes.items():
                if name in line.lower():
                    detected.append(name)
        if detected:
            return list(set(detected))
    except Exception as e:
        print(f"Hailo detection failed: {e}, using fallback")

    # Fallback: return placeholder items for testing
    return ["eggs", "tomatoes", "cheese"]

def ask_ollama(items, cuisine):
    """Send detected items + cuisine to Ollama, return recipe."""
    if not items:
        return "No food detected. Try again."

    items_str = ", ".join(items)
    prompt = (
        f"I have these ingredients: {items_str}. "
        f"Suggest ONE simple {cuisine} recipe in exactly 2 short sentences. "
        f"Be specific and concise."
    )

    print(f"Asking Ollama: {prompt}")
    lcd_print("Thinking...", cuisine)

    try:
        result = subprocess.run(
            ["ollama", "run", "llama3.2:3b", prompt],
            capture_output=True, text=True, timeout=30
        )
        recipe = result.stdout.strip()
        print(f"Ollama response: {recipe}")
        return recipe
    except subprocess.TimeoutExpired:
        return "Timeout. Try again."
    except Exception as e:
        return f"Error: {str(e)[:20]}"

def scroll_lcd(text, delay=0.4):
    """Scroll long text across both LCD lines."""
    # Split into 16-char chunks for display
    words = text.split()
    line1 = ""
    line2 = ""
    buffer = []

    for word in words:
        if len(line1) + len(word) + 1 <= 16:
            line1 += (" " if line1 else "") + word
        elif len(line2) + len(word) + 1 <= 16:
            line2 += (" " if line2 else "") + word
        else:
            buffer.append((line1, line2))
            line1 = word
            line2 = ""

    if line1 or line2:
        buffer.append((line1, line2))

    for l1, l2 in buffer:
        lcd_print(l1, l2)
        time.sleep(delay)

# ─── BUTTON CALLBACKS ─────────────────────────────────────────────
def on_chinese():
    global cuisine
    cuisine = "Chinese"
    lcd_print("Cuisine:", "Chinese")
    print("Cuisine: Chinese")

def on_italian():
    global cuisine
    cuisine = "Italian"
    lcd_print("Cuisine:", "Italian")
    print("Cuisine: Italian")

def on_japanese():
    global cuisine
    cuisine = "Japanese"
    lcd_print("Cuisine:", "Japanese")
    print("Cuisine: Japanese")

def on_deploy():
    global arm_down
    if not arm_down:
        # Deploy arm and scan
        arm_down = True
        deploy_arm()
        time.sleep(0.5)

        # Capture and detect
        lcd_print("Scanning...", "")
        frame = capture_frame()
        if frame is None:
            lcd_print("Camera error!", "Check USB cam")
            retract_arm()
            arm_down = False
            return

        items = detect_food(frame)
        print(f"Detected: {items}")
        lcd_print("Detected:", ", ".join(items)[:16])
        time.sleep(1.5)

        # Get recipe from Ollama
        recipe = ask_ollama(items, cuisine)

        # Display recipe scrolling
        scroll_lcd(recipe, delay=2.5)

    else:
        # Retract arm
        arm_down = False
        retract_arm()
        lcd_print("Ready!", f"Cuisine: {cuisine[:9]}")

btn_deploy.when_pressed   = on_deploy
btn_chinese.when_pressed  = on_chinese
btn_italian.when_pressed  = on_italian
btn_japanese.when_pressed = on_japanese

# ─── STARTUP ──────────────────────────────────────────────────────
print("Fridge Assistant starting...")

# Park arm at startup
move_arm(*ARM_PARKED, delay=1.0)

lcd_print("Fridge Assistant", "Ready!")
print("Ready. Press a cuisine button then deploy.")
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

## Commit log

2026-09-05 Add CAD Files
    CAD Files for fridge assistant arm and base
    [APC base plate v3.dxf, link 1 v6.stl, link 2 v3.stl]
2026-09-05 Organize cad folder
    [APC base plate v3.dxf]
